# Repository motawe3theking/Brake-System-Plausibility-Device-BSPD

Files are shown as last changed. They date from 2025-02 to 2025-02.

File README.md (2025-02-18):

# Brake System Plausibility Device (BSPD)

## Overview
This project implements a standalone, non-programmable **Brake System Plausibility Device (BSPD)** designed for Formula Student Electric Vehicles (EVs). The BSPD monitors the brake system pressure and power delivery to ensure safe isolation of the tractive system during hard braking, complying with Formula Student rules.

## Features
- **Non-Programmable Design:** Implemented using analog components, comparators, and RC-Comparator delay circuits for increased safety and compliance.
- **Hall Effect Current Sensor:** Utilizes the **L06P S05 TAMURA** current sensor to detect power delivery ≥ 5kW.
- **Brake Pressure Sensor:** Ensures accurate detection of hard braking conditions without causing wheel lockup (<= 30 bar).
- **Fault Latching and Reset:** Fault state is latched and maintained until a 10s timer elapses or the LVMS is power-cycled.
- **Simulation and Prototyping:** Designed and tested using LTspice, with multiple prototype iterations for optimal performance.

## Technology and Components Used
- **Current Sensor:** Hall Effect Sensor (L06P S05 TAMURA)
- **Comparators and Logic ICs:** LM358 Op-Amps, SN74HCS4075 OR Gate
- **Timer and Relay:** NE555 Timer, T90 Relay (SLA-12VDC-SL-A)
- **Voltage Regulation:** LM7805CT Voltage Regulator
- **PCB Design:** Designed using Altium
- **Simulation Tool:** LTspice for circuit simulation and testing

## Formula Student Rule Compliance
The BSPD complies with the following rules:
- **T11.6.1:** Opens the shutdown circuit when hard braking occurs while delivering ≥ 5kW power to the motors.
- **T11.6.5:** Uses a brake system pressure sensor to detect hard braking.
- **T11.6.6:** Measures power delivery using a DC circuit current sensor equivalent to 5kW.
- **T11.6.9:** The function is provable during technical inspection with appropriate signal simulation.
- **T11.6.10:** BSPD is designed to be installed outside the TSAC.
- **T11.9.2:** Ensures safe or error states during single failures in the SCS.

## How It Works
1. **Power Cycling:** The BSPD is initialized upon power cycling the LVMS.
2. **Sensor Check:** Sensors are validated within 0.5s using comparators connected to the negative terminal.
3. **Fault Detection and Latching:**
   - If a fault is detected:
     - The state is latched (low logic) and the BSPD LED is triggered.
     - A 10s timer (using NE555) is activated.
     - The shutdown circuit remains open until the timer finishes or the LVMS is power-cycled.
   - If no fault is detected:
     - The BSPD relay is energized.
     - The state is latched (high logic) to maintain normal operation.
4. **Safety and Reset:** The system safely latches errors and resets only when the fault condition is cleared for more than 10s.


## Design and Prototyping
### First Prototype


- Implemented basic RC-Comparator delay circuits and fault latching.

### Second Prototype


- Enhanced with sensor short-circuit detection.
- Reduced the number of transistors by using **SN74HCS4075 OR Gate** from Texas Instruments.
- Replaced standard op-amp with **LM358 Comparator**.

### Third Prototype



- Added a CMOS NOT gate and replaced the buck converter with an **LM7805CT Voltage Regulator**.
- Improved reliability and reduced space usage on the PCB.

## PCB Design and BOM
- PCB designed with compact layout and mounting holes.
- 

- **Bill of Materials (BOM):**
  - T90 Relay (SLA-12VDC-SL-A)
  - OR Gate (SN74HCS4075)
  - Op-Amps (LM358)
  - NE555 Timer
  - 4 NPN Transistors
  - LM7805CT Voltage Regulator

## Future Improvements
- Replace the CMOS NOT gate with a more efficient logic solution.
- Finalize BOM with Egyptian currency for local sourcing.

## Installation and Usage
1. **Clone the Repository:**
   ```bash
   git clone https://github.com/motawe3theking/Brake-System-Plausibility-Device-BSPD.git
   cd Brake-System-Plausibility-Device-BSPD

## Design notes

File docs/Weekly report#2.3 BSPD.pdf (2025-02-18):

Weekly report | Report #2.3

## BSPD

## Rule Analysis:

T11.6.1
A standalone non-programmable circuit, the BSPD, must open the shutdown circuit, see EV6.1 and CV4.1, when hard braking occurs, whilst:
- [EV ONLY] ≥5 kW power is delivered to the motors,
- [CV ONLY] The throttle position is more than 25% over idle position.
The shutdown circuit must remain open until power cycling the LVMS or the BSPD may reset itself if the opening condition is no longer present for more than 10s.

Comments:
BSPD must be implemented on a PCB using unprogrammable components like an ECU.
T11.6.5 To detect hard braking, a brake system pressure sensor must be used. The threshold must be chosen such that there are no locked wheels, and the brake pressure is <= 30bar.
T11.6.6 [EV ONLY] To measure power delivery, a DC circuit current sensor only must be used. The threshold must be chosen to an equivalent of 5kW for maximum TS voltage.
Power cycling is switching the LVMS off and on.
Will need to implement a timer for the 10s.

T11.6.9
[EV ONLY] The team must prove the function of the BSPD during technical inspection by sending an appropriate signal that represents the current, in order to achieve 5 kW whilst pressing the brake pedal. This test must prove the functionality of the complete BSPD except for any commercially available current sensors.
IN4.2.1 The following items must be presented at electrical inspection:
- Tools needed for the BSPD check, see T11.6.9

Comments:
After the circuit is finished, we will develop the test procedure based on this rule.

T11.6.10
[EV ONLY] The BSPD including all required sensors must not be installed inside the TSAC

Comments:
Not within the accumulator container.

T11.9.2
Any of the following SCS single failures must result in a safe or error state of all connected systems:
- Failures of signals transmitted by cable:
i. Open circuit, ii. Short circuit to ground.
- Failures of analogue sensor signals transmitted by cable:
i. Short circuit to supply voltage.

## Process flow chart:

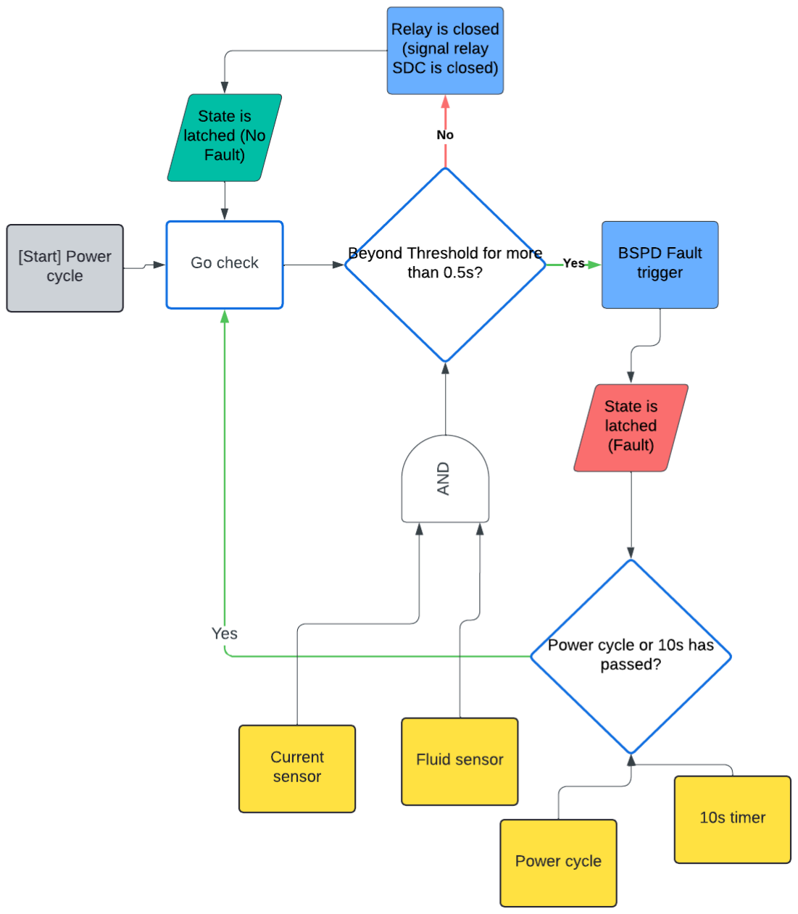
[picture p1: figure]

1. [start] Circuit is power cycled.
2. Sensors are checked (0.5s condition) [Two comparators with sensors on the -ve
terminal. Goes into an RC-Comparator delay circuit. Goes through an AND gate.]
If fault:
A. Fault triggered (BSPD LED)
B. State is Latched (Logic is Low ie.: a reversed latch, because the relay is normally open)
C. 555 timer for 10s
If Power cycled or timer finishes:
- Go back to step 2.

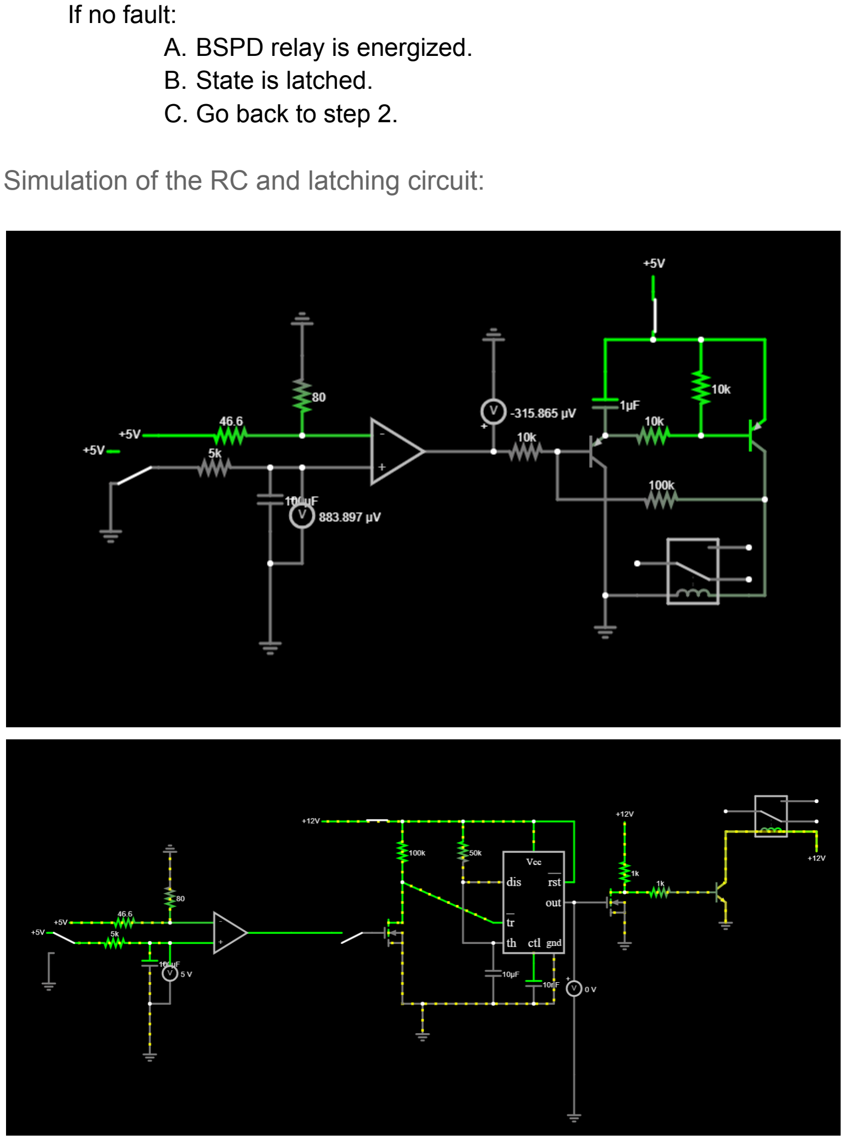
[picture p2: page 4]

If no fault:
A. BSPD relay is energized.
B. State is latched.
C. Go back to step 2.

Simulation of the RC and latching circuit:

## Ltspice:

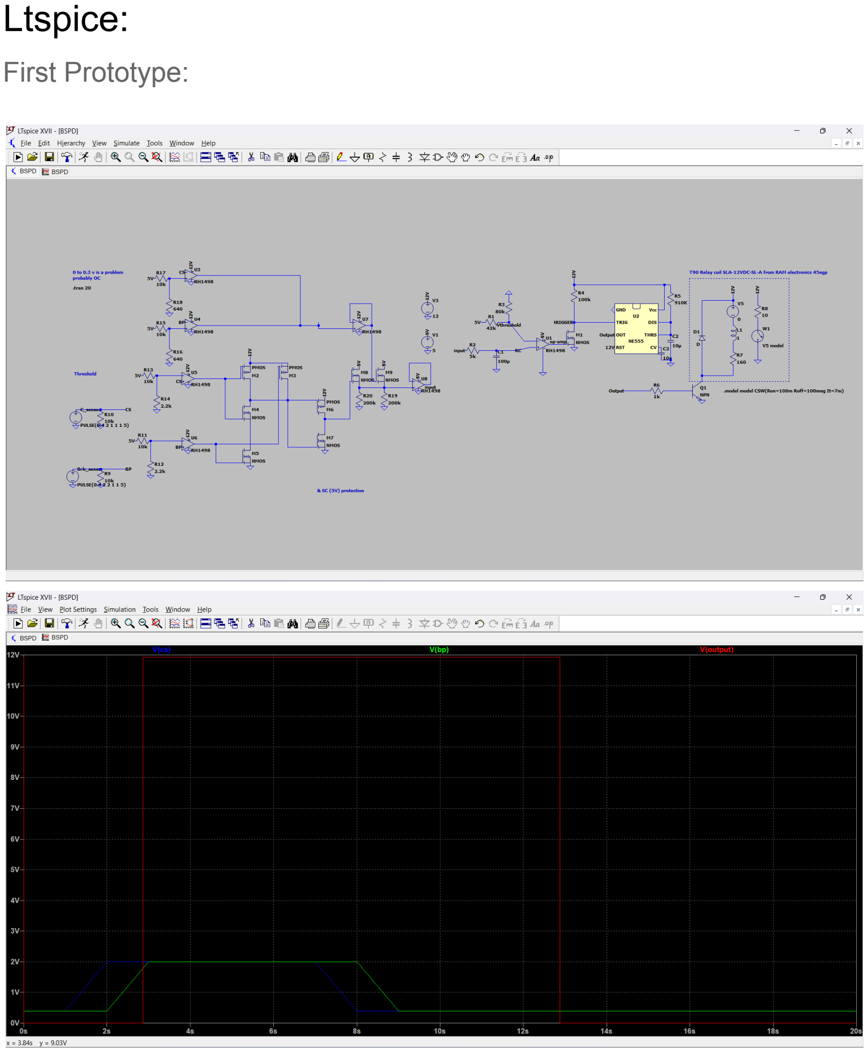
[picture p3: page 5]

First Prototype:

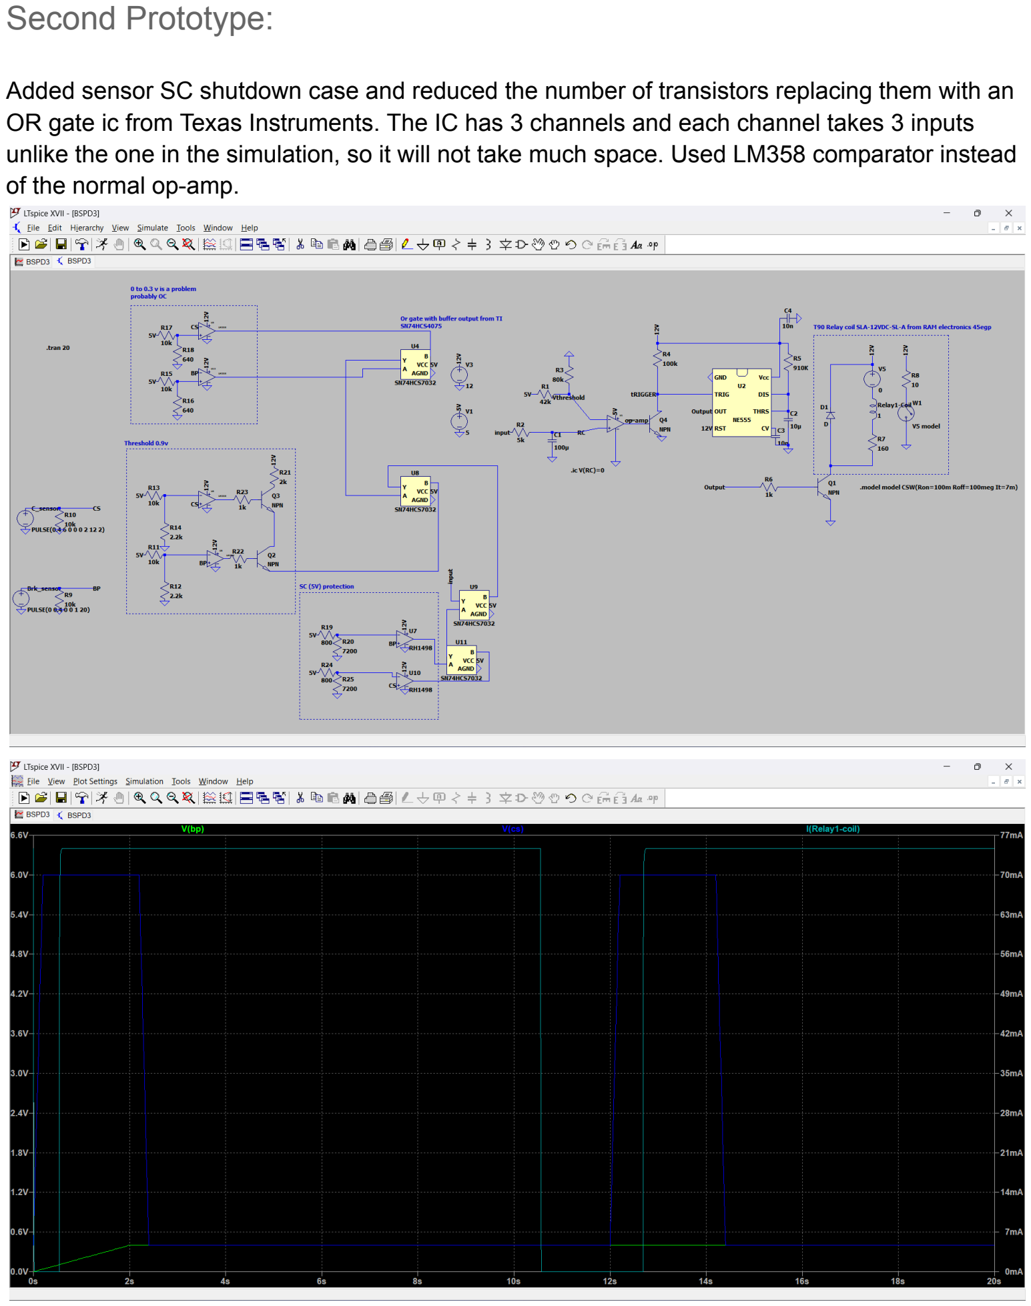
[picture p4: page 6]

Second Prototype:

Added sensor SC shutdown case and reduced the number of transistors replacing them with an OR gate ic from Texas Instruments. The IC has 3 channels and each channel takes 3 inputs unlike the one in the simulation, so it will not take much space. Used LM358 comparator instead of the normal op-amp.

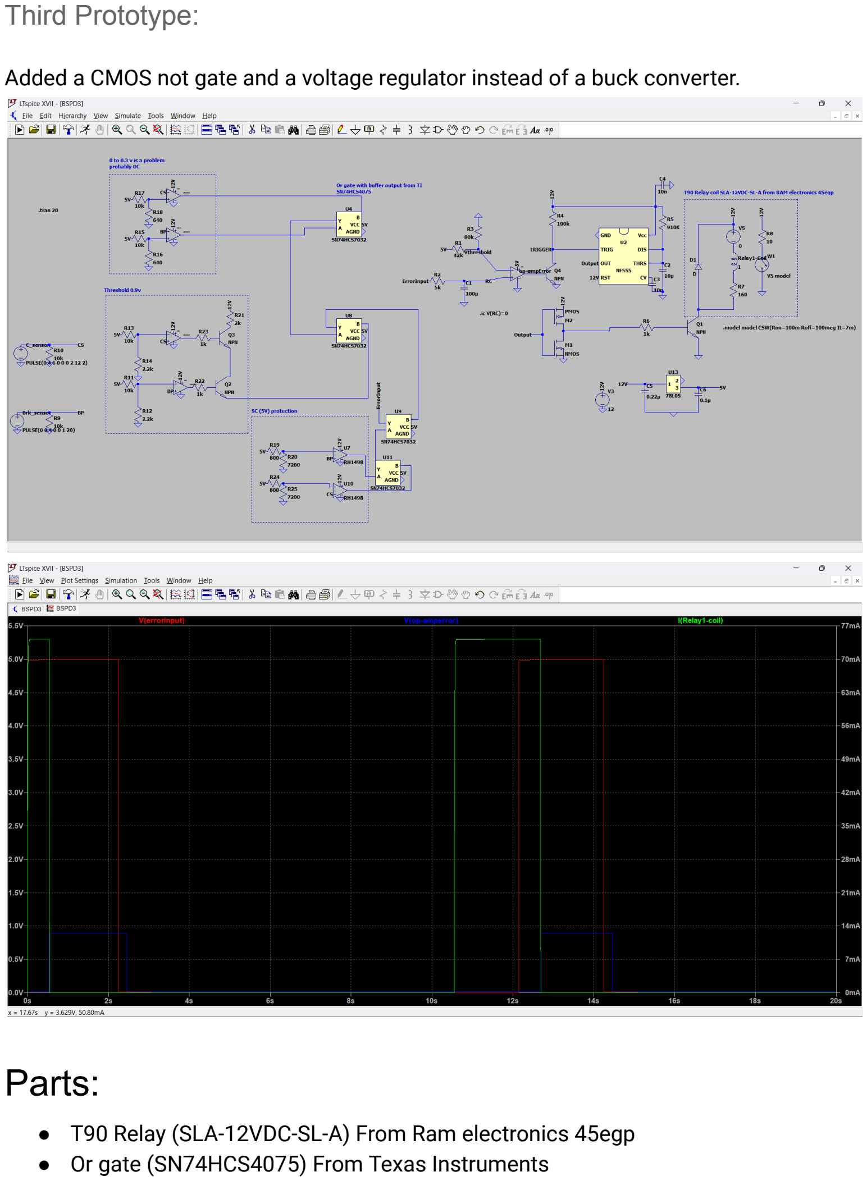
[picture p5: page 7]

Third Prototype:

Added a CMOS not gate and a voltage regulator instead of a buck converter.

## Parts:

- T90 Relay (SLA-12VDC-SL-A) From Ram electronics 45egp
- Or gate (SN74HCS4075) From Texas Instruments

- Op-amps (LM358)
- NE555
- 4 NPNs
- LM7805CT

## Schematic:

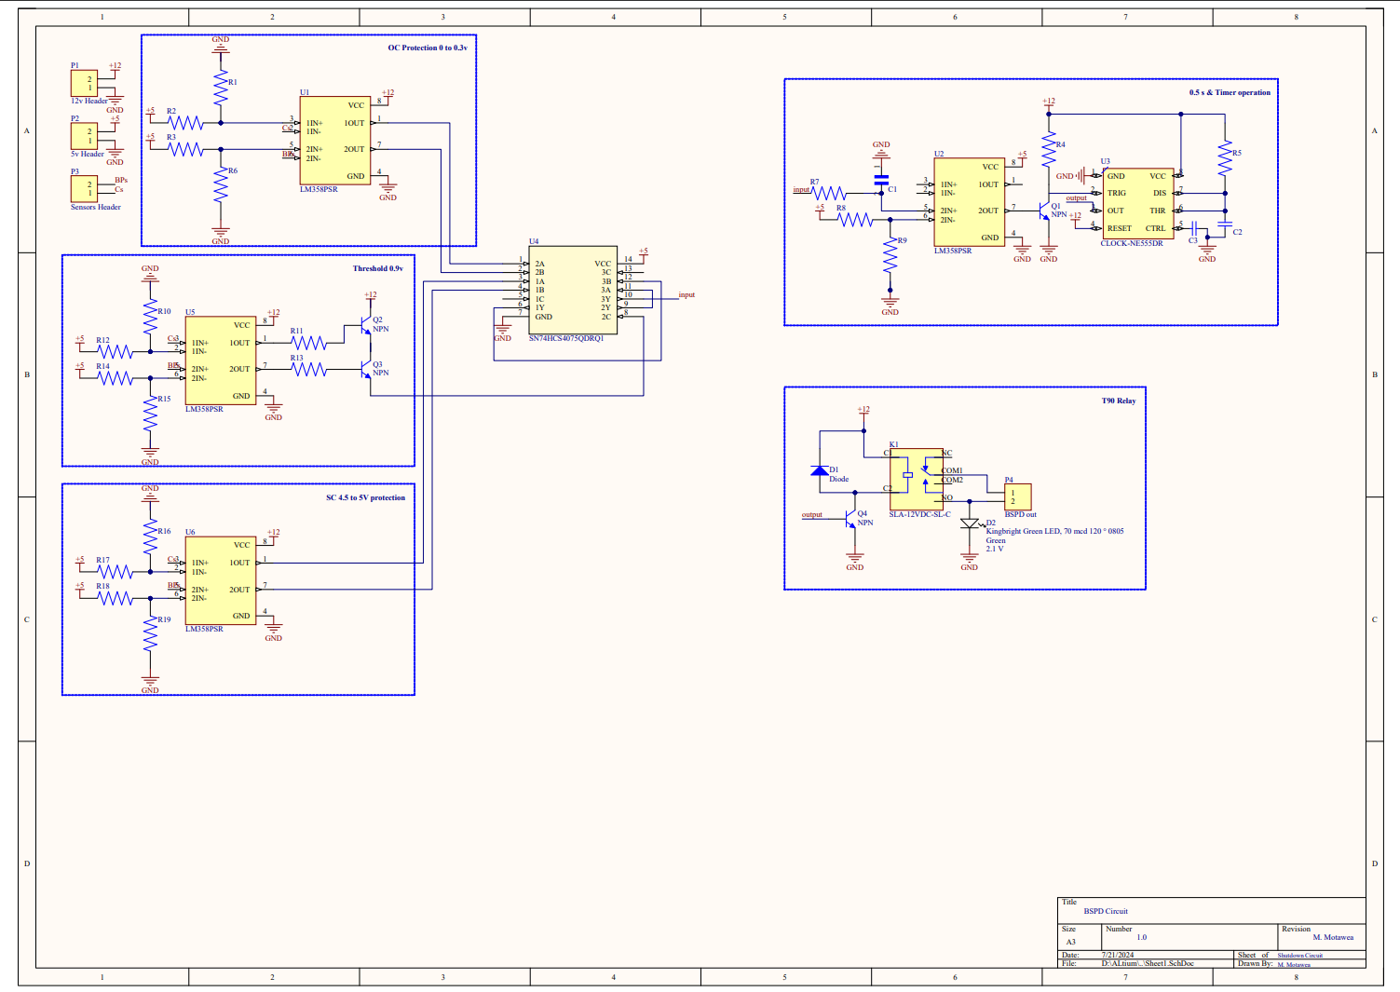
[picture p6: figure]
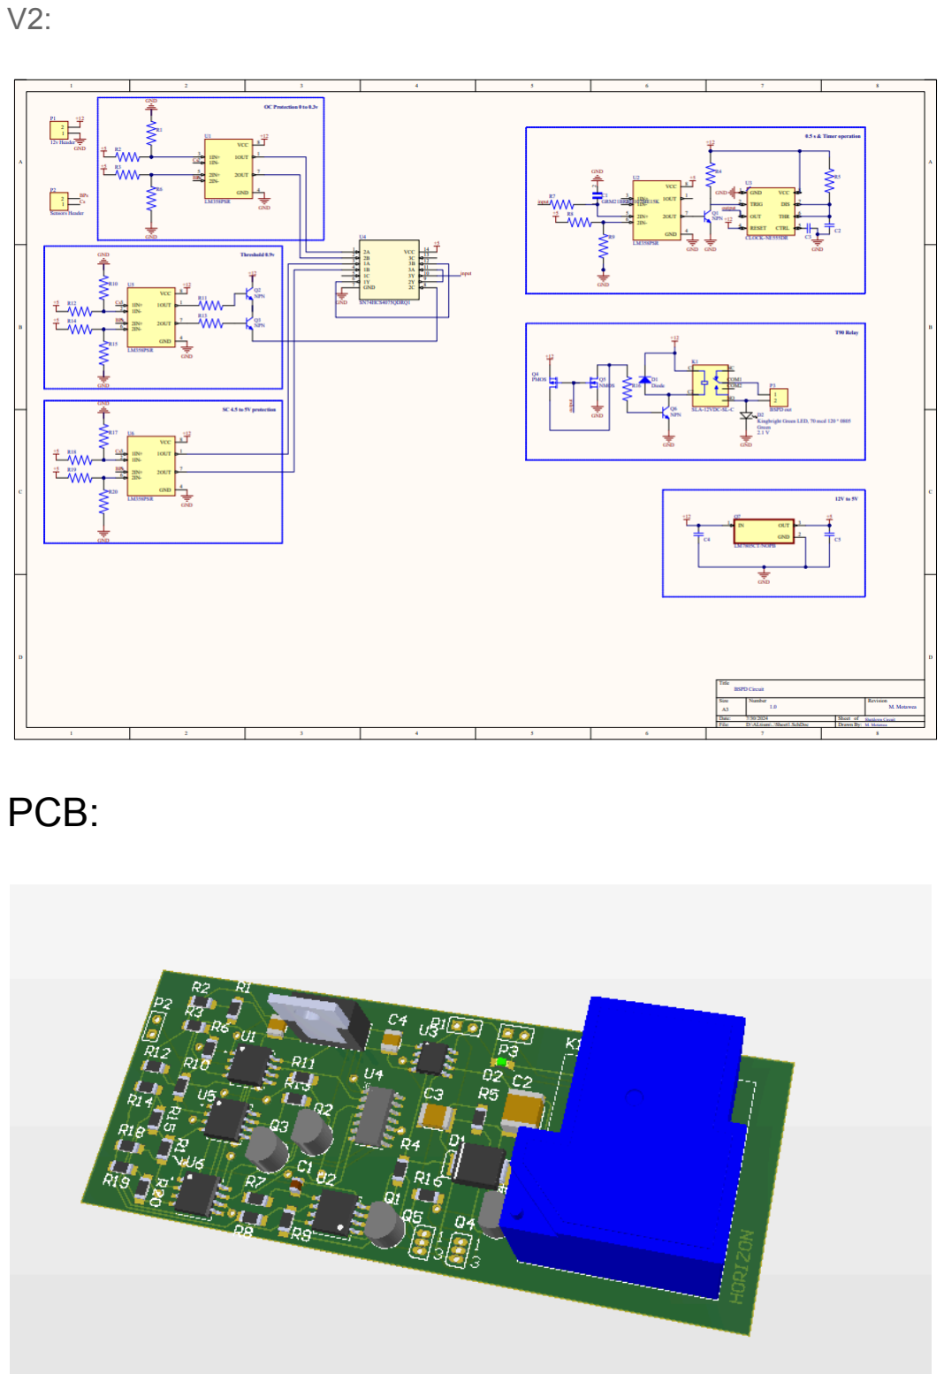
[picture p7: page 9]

V2:

## PCB:

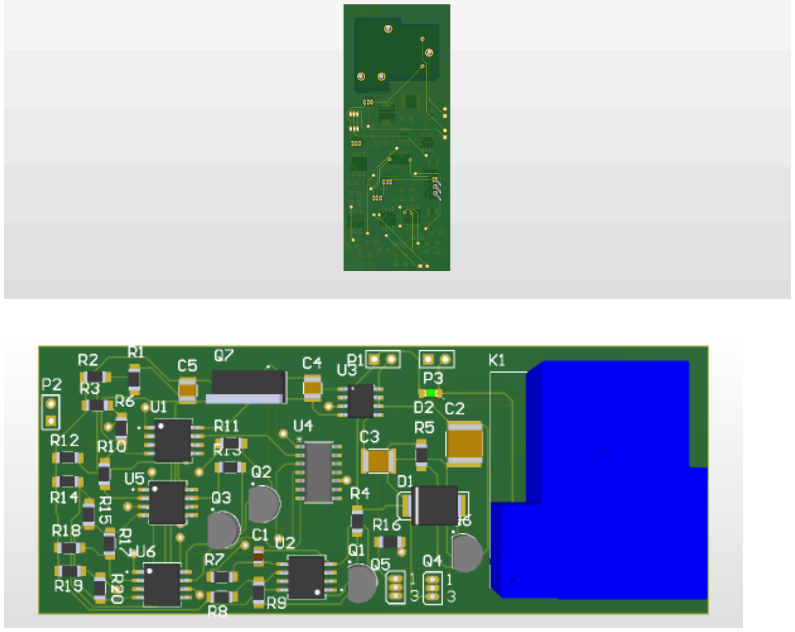
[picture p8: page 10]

## BOM:

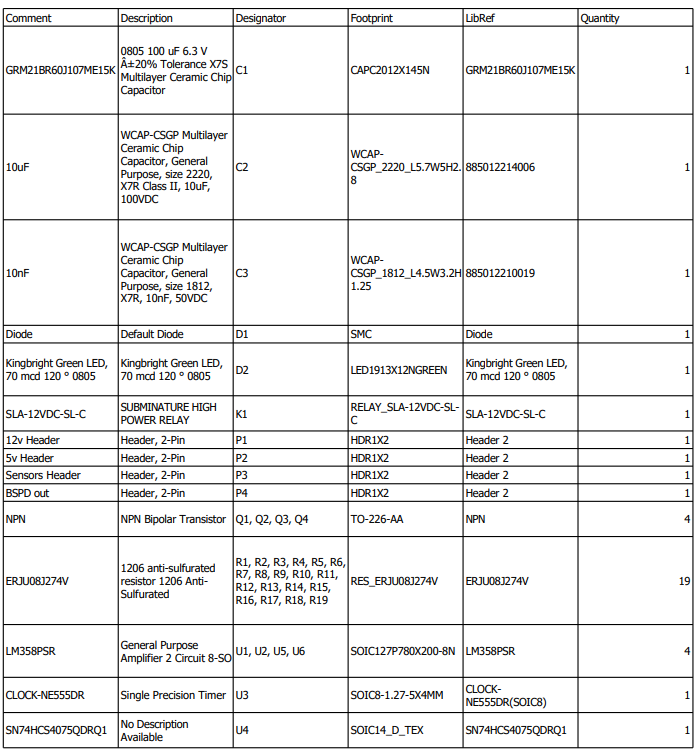
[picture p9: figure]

Updated BOM:

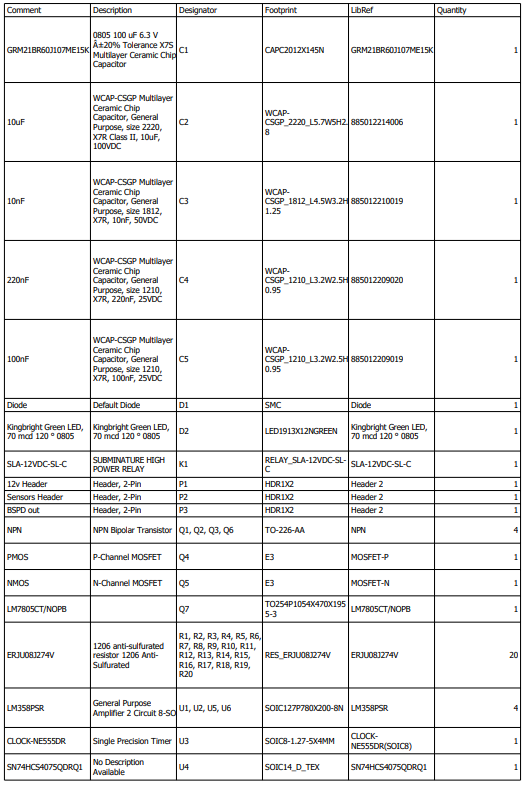
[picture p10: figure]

Will be updated with Egyptian currency.

## Sensors:

-Current sensor [Hall effect] | L06P S05 TAMURA
Model will be chosen according to battery voltage.

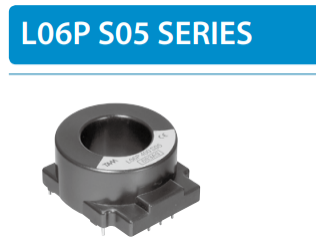
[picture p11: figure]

Reference current will be calculated after the Battery is done. Connector: MOLEX 5.08mm Pitch KK Crimp Housing, 3 Circuits, Natural

-BP sensor

## To do:

Timer
A faster path for RC discharge
Ltspice
Buck converter
Parts and sensors selection [add to BOM]
Make sure transistors are compatible with relays and every thing Schematic design
BOM
PCB
Mounting holes
fuse

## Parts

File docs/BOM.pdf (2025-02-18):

Comment | Description | Designator | Footprint | LibRef | Quantity
GRM21BR60J107ME15K | 0805 100 uF 6.3 V Â±20% Tolerance X7S Multilayer Ceramic Chip Capacitor | C1 | CAPC2012X145N | GRM21BR60J107ME15K | 1
10uF | WCAP-CSGP Multilayer Ceramic Chip Capacitor, General Purpose, size 2220, X7R Class II, 10uF, 100VDC | C2 | WCAP-CSGP_2220_L5.7W5H2. 8 | 885012214006 | 1
10nF | WCAP-CSGP Multilayer Ceramic Chip Capacitor, General Purpose, size 1812, X7R, 10nF, 50VDC | C3 | WCAP-CSGP_1812_L4.5W3.2H 1.25 | 885012210019 | 1
220nF | WCAP-CSGP Multilayer Ceramic Chip Capacitor, General Purpose, size 1210, X7R, 220nF, 25VDC | C4 | WCAP-CSGP_1210_L3.2W2.5H 0.95 | 885012209020 | 1
100nF | WCAP-CSGP Multilayer Ceramic Chip Capacitor, General Purpose, size 1210, X7R, 100nF, 25VDC | C5 | WCAP-CSGP_1210_L3.2W2.5H 0.95 | 885012209019 | 1
Diode | Default Diode | D1 | SMC | Diode | 1
Kingbright Green LED, 70 mcd 120 ° 0805 | Kingbright Green LED, 70 mcd 120 ° 0805 | D2 | LED1913X12NGREEN | Kingbright Green LED, 70 mcd 120 ° 0805 | 1
SLA-12VDC-SL-C | SUBMINATURE HIGH POWER RELAY | K1 | RELAY_SLA-12VDC-SL-C | SLA-12VDC-SL-C | 1
12v Header | Header, 2-Pin | P1 | HDR1X2 | Header 2 | 1
Sensors Header | Header, 2-Pin | P2 | HDR1X2 | Header 2 | 1
BSPD out | Header, 2-Pin | P3 | HDR1X2 | Header 2 | 1
NPN | NPN Bipolar Transistor | Q1, Q2, Q3, Q6 | TO-226-AA | NPN | 4
PMOS | P-Channel MOSFET | Q4 | E3 | MOSFET-P | 1
NMOS | N-Channel MOSFET | Q5 | E3 | MOSFET-N | 1
LM7805CT/NOPB | | Q7 | TO254P1054X470X195 5-3 | LM7805CT/NOPB | 1
ERJU08J274V | 1206 anti-sulfurated resistor 1206 Anti-Sulfurated | R1, R2, R3, R4, R5, R6, R7, R8, R9, R10, R11, R12, R13, R14, R15, R16, R17, R18, R19, R20 | RES_ERJU08J274V | ERJU08J274V | 20
LM358PSR | General Purpose Amplifier 2 Circuit 8-SO | U1, U2, U5, U6 | SOIC127P780X200-8N | LM358PSR | 4
CLOCK-NE555DR | Single Precision Timer | U3 | SOIC8-1.27-5X4MM | CLOCK-NE555DR(SOIC8) | 1
SN74HCS4075QDRQ1 | No Description Available | U4 | SOIC14_D_TEX | SN74HCS4075QDRQ1 | 1

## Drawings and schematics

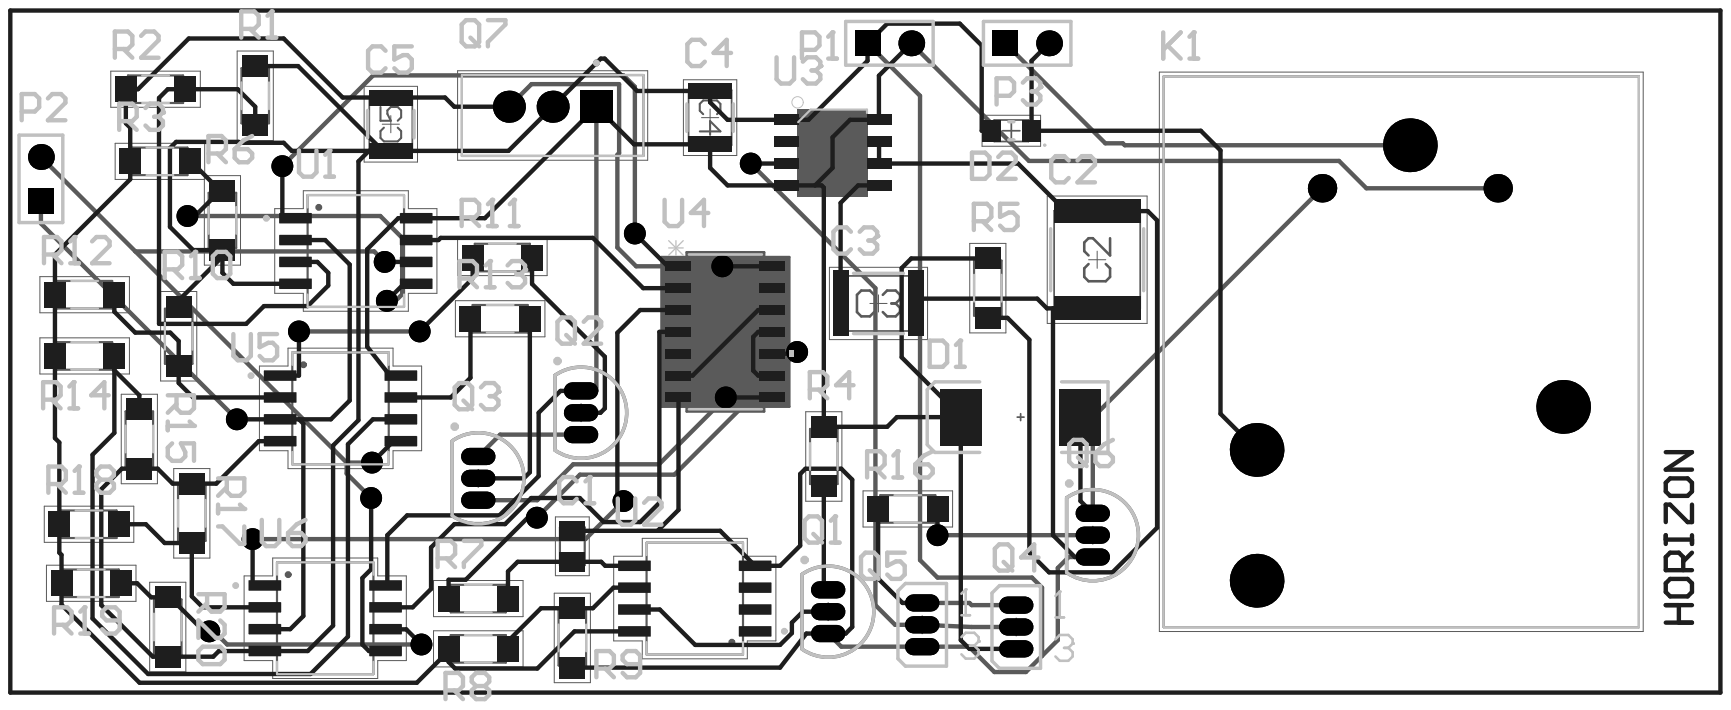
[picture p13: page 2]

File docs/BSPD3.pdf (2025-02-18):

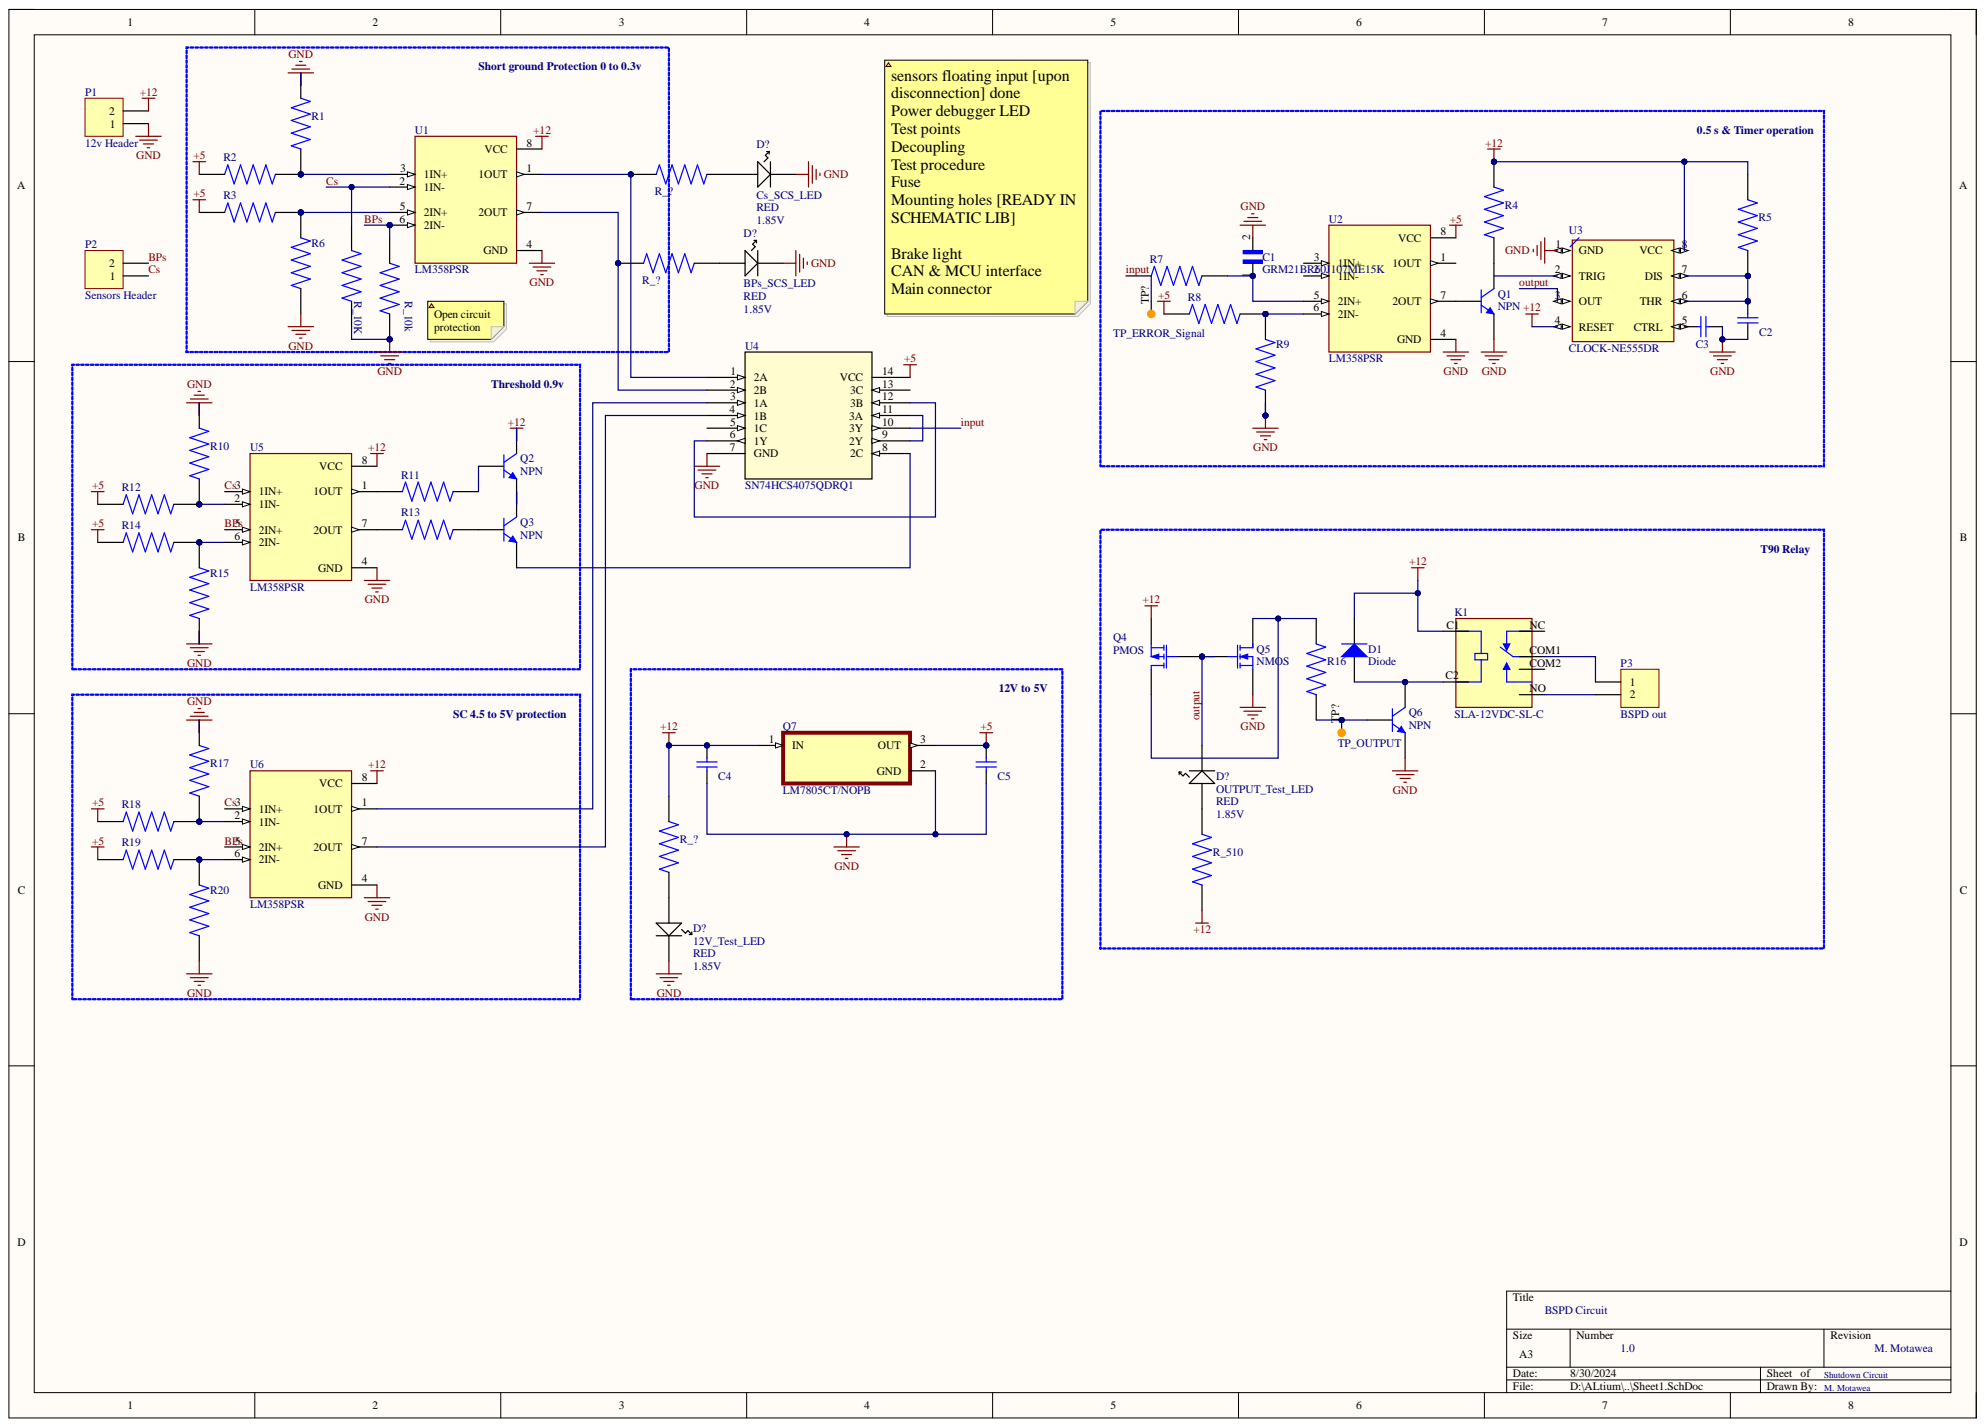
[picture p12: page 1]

Short ground Protection 0 to 0.3v

sensors floating input [upon
disconnection] done Power debugger LED Test points
